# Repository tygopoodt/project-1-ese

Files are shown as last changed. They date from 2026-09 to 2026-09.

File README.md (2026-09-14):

<p align="center">
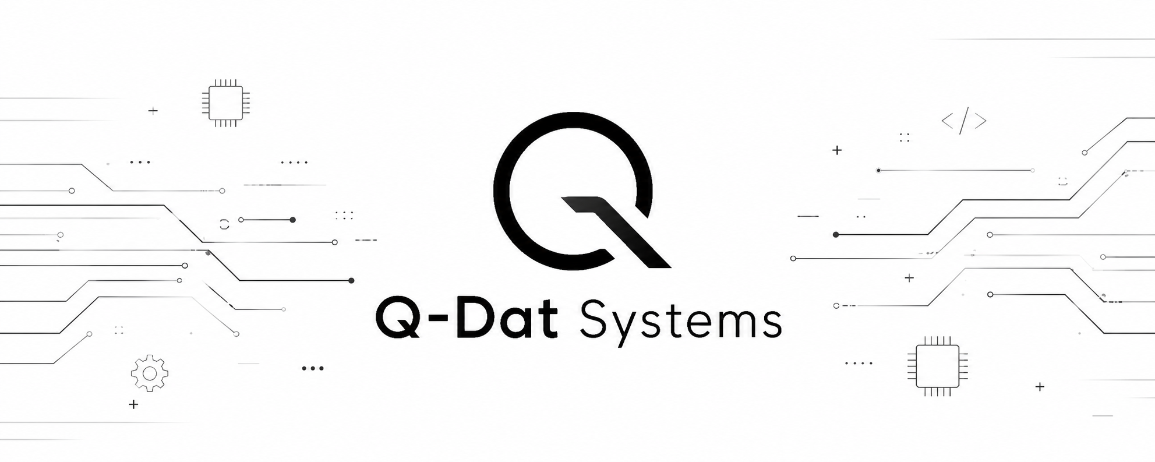
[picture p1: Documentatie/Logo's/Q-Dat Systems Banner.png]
Q-Dat Systems
  
</p>

<h1 align="center">Robot-car</h1>

<p align="center">
  <em>Project 1 NL &middot; Embedded Systems Engineering &middot; HAN</em>
</p>

<p align="center">
  
  
  
  
</p>

---

## Over het project

Transport wordt steeds verder geautomatiseerd. Voor opdrachtgever Robot-car-Gadgets
ontwikkelt **Q-Dat Systems** een prototype van de **Robot-car**: een autonoom rijdende
modelauto op basis van een ATmega328P.

De auto rijdt vooruit, achteruit en draait om zijn as, volgt een zwarte lijn op de vloer,
houdt afstand tot een voorganger en is via remote control te besturen. De motoren worden
met PWM via een L298N H-brug aangestuurd; bediening en tests lopen over de USART.

Het project beslaat twee perioden. In de eerste periode verkennen we de functionaliteit met
rapid prototyping in de Arduino IDE. In de tweede periode gaat dezelfde microcontroller
opnieuw op de tekentafel, nu in C met directe registermanipulatie.

## Repository

| Map | Inhoud |
| --- | --- |
| `Software/` | Firmware voor de ATmega328P |
| `Hardware/` | Schema's, componentkeuzes en het 3D-model van het chassis |
| `Documentatie/` | Functioneel ontwerp, MoSCoW-eisen, planning, notulen en huisstijl-templates |
| `Documentatie/Logo's/` | Logo's, banner en logo-animatie Q-Dat Systems |
| `Documentatie/Schetsen/` | UI-schetsen van bediening, displays en gedrag |
| `Documentatie/Frame-analyse/` | Analyse van frame, spoorbreedte en massa |
| `Documentatie/Simulatie Onderzoek/` | MATLAB-simulaties voor lijnvolgen en obstakeldetectie |
| `Documentatie/SchoolDocumenten_Project/` | Projecthandleiding, beoordelingsformulieren en richtlijnen |

## Kernvereisten

- **T1** ATmega328P als microcontroller
- **T2/T3** Programmeren in C, volgens de C-stijl- en programmeerrichtlijnen, code in het Engels
- **T4** DC-motoren via een L298N H-brug, snelheid geregeld met PWM
- **T5** Besturing en tests via de USART
- **T6** Voeding uit batterijen, met polariteits- en kortsluitbeveiliging
- **B1** Maximaal &euro;50,- aan aanvullende componenten

## Team

Projectgroep **Q-Dat Systems**:

Mohammed &middot; Tygo &middot; Floris &middot; Milan &middot; Mathijs &middot; Nathan

---

<p align="center">
  <sub>Q-Dat Systems &middot; Academie Engineering en Automotive &middot; Hogeschool van Arnhem en Nijmegen</sub>
</p>

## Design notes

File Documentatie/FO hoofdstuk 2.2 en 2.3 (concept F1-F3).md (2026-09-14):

# Functioneel ontwerp — aanvulling hoofdstuk 2.2 en 2.3

**Status:** concept, uitgewerkt voor F1, F2 en F3. Wordt aangevuld zodra F4 tot en met F7 zijn vastgesteld.
**Bron van de eisen:** Projecthandleiding PROJ1-V v1.0, §3.5 (concept technische eisen T1–T7 en budgeteis B1) en §3.7 en §3.11.
**Doel:** de twee subparagrafen die het Template productrapport v1.4 voor hoofdstuk 2 voorschrijft, maar die nu nog ontbreken.

---

## 2.2 Technische specificaties

Naast de functionele specificaties uit paragraaf 2.1 stelt de opdrachtgever een aantal aanvullende eisen aan het product zelf: de te gebruiken microcontroller, de programmeertaal, de manier waarop de motoren worden aangedreven en de wijze van voeding. Deze technische specificaties beschrijven waaraan het product moet voldoen, niet hoe wij dat gaan realiseren; die uitwerking volgt in hoofdstuk 3.

De nummering T1 tot en met T7 komt overeen met de concept technische eisen uit de projecthandleiding, zodat de opdrachtgever zijn eigen eisen terugvindt. T8 tot en met T11 zijn door ons toegevoegd omdat de functionele specificaties uit paragraaf 2.1 daar niet zonder kunnen. De kolom *Herleidbaar naar* verwijst naar de functionele specificatie die de betreffende technische eis mogelijk maakt.

### Tabel 2 — SMART technische specificaties

| # | MoSCoW | Omschrijving | Herleidbaar naar |
|---|---|---|---|
| T1 | M | De besturing van de robot-car wordt gerealiseerd met een ATmega328(p)-microcontroller. | F1, F2, F3 |
| T1.1 | M | In periode 1 wordt het tussenproduct via rapid prototyping gerealiseerd met de Arduino IDE op dezelfde ATmega328(p); in periode 2 wordt de microcontroller aangestuurd door rechtstreeks de registers te bewerken. | F1, F2, F3 |
| T2 | M | De software voor de microcontroller wordt geschreven in de programmeertaal C. | F1, F2, F3 |
| T3 | M | De C-code voldoet aan de programmeerrichtlijnen zoals aangeleerd in de opleiding (C-style programming guidelines v3.1). | F1, F2, F3 |
| T4 | M | De dc-motoren van de robot-car worden aangedreven via een H-brug, zodat beide draairichtingen per motor mogelijk zijn. | F1.1, F1.2 |
| T4.1 | M | Voor het regelen van de motorsnelheid wordt gebruikgemaakt van de PWM van de microcontroller; er wordt geen aanvullende hardware voor snelheidsregeling toegepast. | F1.3 |
| T4.2 | M | Voor de H-brug wordt gebruikgemaakt van een L298N dual H-bridge driverboard. | F1.1, F1.2 |
| T4.3 | M | De robot-car wordt aangedreven door de vier dc-motoren van het door de opdrachtgever geleverde chassis. | F1 |
| T5 | M | Voor testdoeleinden kan de robot-car bestuurd worden via de seriële interface, de USART van de ATmega328(p). | F1, F2.5 |
| T5.1 | M | Via de USART kan de robot-car vooruit en achteruit rijden. | F1.1 |
| T5.2 | M | Via de USART kan de robot-car links- en rechtsom draaien. | F1.2 |
| T5.3 | M | Via de USART kan de rijsnelheid van de robot-car worden ingesteld. | F1.3 |
| T5.4 | M | Via de USART kan de autonome mode worden gestart en gestopt. | F2.5 |
| T6 | M | Voor de voeding van de robot-car wordt gebruikgemaakt van batterijen. | F1, F2, F3 |
| T6.1 | M | De schakeling is beveiligd tegen het verkeerd om aansluiten van de voeding. | – |
| T6.2 | M | De batterijen zijn beveiligd tegen kortsluiting door een beveiliging die zo dicht mogelijk bij de batterij is geplaatst. | – |
| T6.3 | M | Een LED geeft aan dat de robot-car wordt gevoed; deze LED brandt continu zolang de robot-car is ingeschakeld. | F1, F2, F3 |
| T6.4 | M | De voedingsspanning van de microcontroller blijft binnen het door de fabrikant toegestane bereik, ook wanneer alle vier de motoren gelijktijdig maximaal worden belast. | F1, F2, F3 |
| T6.5 | C | De batterijspanning is voor de microcontroller meetbaar, zodat het batterijniveau kan worden weergegeven. | F5.4 |
| T7 | M | De achterzijde van de robot-car is voorzien van een reflector, zodat deze robot-car op zijn beurt door een andere robot-car gevolgd kan worden. | F3.2 |
| T8 | M | De robot-car meet de vrije ruimte recht vooruit met een afstandssensor. | F2.1 t/m F2.4, F3.2 |
| T8.1 | M | De afstandssensor heeft een meetbereik van ten minste 10 tot 50 cm. | F2.2, F3.2 |
| T8.2 | M | De afstandssensor levert ten minste 5 metingen per seconde. | F2.2 |
| T9 | M | De robot-car detecteert de te volgen lijn met een lijnsensor aan de onderzijde van het chassis. | F3.1 |
| T9.1 | M | De lijnsensor detecteert zwart tape van 1 tot 2 cm breed op het linoleum van de gang op de begane grond van gebouw R29. | F3.1 |
| T9.2 | M | De lijnsensor kan onderscheiden of de lijn zich links van, onder, of rechts van het midden van de robot-car bevindt, zodat de afwijking kan worden bijgestuurd. | F3.1 |
| T10 | M | De robot-car is voorzien van handbediening op de auto zelf, bestaande uit een display en bedieningstoetsen. | F5, F6 |
| T10.1 | M | Het display geeft vier regels gelijktijdig weer, volgens de regelindeling van figuur 2. | F5.1 t/m F5.4 |
| T10.2 | S | De bediening bestaat uit drie toetsen: omhoog, omlaag en OK. | F6 |
| T11 | C | Aan de achterzijde van de robot-car zitten twee LED's, links en rechts, die de draairichting aangeven. | F1.4 |

### Tabel 3 — Budgeteisen

| # | MoSCoW | Omschrijving | Herleidbaar naar |
|---|---|---|---|
| B1 | M | Het chassis met de vier dc-motoren wordt geleverd door de opdrachtgever. | T4.3 |
| B2 | M | De aanvullende kosten voor het prototype bedragen maximaal € 50,- aan onderdelen. Willen wij meer besteden, dan wordt dit vooraf met de tutor overlegd. | T8, T9, T10 |
| B3 | M | Kosten voor het gebruik van het Fablab worden meegenomen in de berekening van de uiteindelijke productiekosten, ook wanneer ze voor het project zelf niet in rekening worden gebracht. | – |

### Open punten bij de technische specificaties

1. **T5.4** — In de concepteisen staat T5.4 zonder omschrijving. Wij hebben deze ingevuld als "de autonome mode kan via de USART worden gestart en gestopt", aansluitend op F2.5. Graag bevestigen of dit is wat u bedoelde.
2. **H-brug** — In §3.5 van de projecthandleiding staat een L298N, in implementatietip 5 een L294n. Wij gaan uit van de L298N; graag bevestigen.
3. **Snelheidsmeting** — Op het beoordelingsformulier staat dat de robot-car sensoren heeft voor het meten van afstand *en snelheid*. In de concepteisen komt snelheidsmeting niet voor. Moet de werkelijke rijsnelheid gemeten worden, of volstaat het instellen van de snelheid via PWM (T4.1)?
4. **T10.1** — Wij stellen een display van vier regels voor, omdat F5.1 tot en met F5.4 samen vier gegevens moeten tonen. Gaat u hiermee akkoord?
5. **T6.5** — Het meten van de batterijspanning staat op Could, in lijn met F5.4. Als u het batterijniveau wel als vaste eis wilt, wordt dit een Must.

---

## 2.3 User interface

In deze paragraaf staat hoe de robot-car er voor de gebruiker uitziet en hoe hij zich gedraagt: welke bedieningselementen er zijn, wat er op het display verschijnt, en wat er aan de uitvoer verandert wanneer de gebruiker of de omgeving iets doet. De schetsen zijn een tweede weergave van dezelfde functionaliteit die in paragraaf 2.1 in tabelvorm staat, en zijn bedoeld om samen met de opdrachtgever vast te stellen dat wij hetzelfde beeld voor ogen hebben. De schetsen zijn niet op schaal en leggen geen componentkeuze vast; die volgt in hoofdstuk 3.

### Figuur 1 — Bedieningselementen en sensoren van de robot-car

*Bestand: `Documentatie/Schetsen/UI-01 Bedieningselementen Robot-car.svg`*

Bovenaanzicht en achteraanzicht van de robot-car met de plaats van de afstandssensor (T8), de lijnsensor (T9), het display en de bedieningstoetsen (T10), de batterijen (T6), de richting-LED's (T11), de voedings-LED (T6.3) en de reflector (T7). De genummerde legenda koppelt elk element aan de specificatie waaruit het voortkomt.

### Figuur 2 — Displayschermen en menustructuur

*Bestand: `Documentatie/Schetsen/UI-02 Displayschermen en menustructuur.svg`*

Deel A legt de vaste regelindeling van het display vast: regel 1 toont de actieve mode en het batterijniveau, regel 2 de rijrichting of de status, regel 3 de tijd in de huidige mode en regel 4 de totale gebruikstijd. Deze indeling is in elke mode gelijk; alleen de inhoud van regel 1 en 2 verandert. Deel B toont het hoofdmenu waarmee de gebruiker een mode kiest (F6) en de schermen die daarbij horen: Autonoom rijdend en Autonoom bij stilstand voor een obstakel (F2), en Slave volgend en Slave wachtend op de voorganger (F3). De schermen voor de handbediening (F4) volgen dezelfde indeling en worden bij F4 uitgewerkt.

### Figuur 3 — Invoer, uitvoer en gedrag van de richting-LED's

*Bestand: `Documentatie/Schetsen/UI-03 Invoer-uitvoer en LED-gedrag.svg`*

Deel A geeft in één overzicht weer welke invoer de robot-car krijgt (bedieningstoetsen, afstandssensor, lijnsensor, USART-commando's) en welke uitvoer hij daarop geeft (display, richting-LED's, voedings-LED, aandrijving). Deel B laat zien wat er met de uitvoer gebeurt als de invoer verandert: zolang de robot-car naar links draait knippert alleen de linker-LED met 50 ms aan en 50 ms uit, en die LED gaat direct uit zodra het draaien stopt (F1.4). De voedings-LED brandt onafhankelijk daarvan continu (T6.3).

### Figuur 4 — Gedrag op het parcours bij F2 en F3

*Bestand: `Documentatie/Schetsen/UI-04 Gedrag F2 autonoom en F3 slave.svg`*

Deel A toont de drie situaties van het autonoom rijden met de bijbehorende maten: doorrijden zolang er recht vooruit ten minste 30 cm vrij is (F2.1), remmen en stoppen bij een obstakel binnen 20 cm met minimaal 2 cm ruimte over (F2.3), en binnen 4 seconden een nieuwe richting kiezen door te draaien of maximaal 30 cm achteruit te rijden (F2.4). Deel B toont de slave mode: de robot-car blijft binnen 5 cm van de lijn (F3.1) en houdt 10 tot 50 cm afstand tot de voorganger, die aan de achterzijde een reflector draagt (F3.2, T7). Bij elke situatie staat wat het display op dat moment toont.

### Open punten bij de user interface

1. **Plaats van display en menu** — Wij gaan ervan uit dat het display en de toetsen op de auto zelf zitten, zoals in figuur 1. Als u ze liever in de afstandsbediening ziet, verandert figuur 1 en figuur 2.
2. **Regel 2 van het display** — In de concepteisen staat de snelheid op het display (F5.2); wij tonen daar nu de rijrichting en de mode. Wilt u de snelheid er alsnog bij, dan is een vijfde regel of een tweede scherm nodig.
3. **Wisselen van mode** — Mag de gebruiker tijdens het rijden van mode wisselen, of moet de robot-car daarvoor eerst stilstaan?
4. **Parcours** — Voor figuur 4 hebben wij de afmetingen van het testparcours en het lijnparcours nodig, en de afmetingen en het materiaal van de obstakels.

---

## Verwerken in het Word-document

De vier schetsen zijn SVG-bestanden. Word 2016 en later ondersteunt SVG rechtstreeks: **Invoegen → Afbeeldingen → Dit apparaat**, en daarna een bijschrift toevoegen via **Verwijzingen → Bijschrift invoegen**, zodat de figuurnummering automatisch meeloopt met de rest van het rapport. De tabellen staan ook als CSV in `Documentatie/Technische eisen MoSCoW.csv` en `Documentatie/Budgeteisen MoSCoW.csv`, in dezelfde opzet als de bestaande `Functionele eisen MoSCoW.csv`.

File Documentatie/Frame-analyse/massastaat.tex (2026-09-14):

\begin{tabular}{lrrrl}
\toprule
Component & $m$ [g] & $x_g$ achter as & $h$ [mm] & Plaats \\
\midrule
2 wielen & 60 & 0 & 32 & op de aandrijfas \\
2 motoren & 60 & 17 & 32 & huis 70 mm, 18 mm voor de as \\
frame + dek (3D-print) & 130 & 25 & 38 & PETG, topologisch geoptimaliseerd \\
accu 4$\times$AA & 110 & 55 & 54 & hoofddek, achter \\
ATmega328P Xplained Mini & 25 & -12 & 54 & hoofddek, voor \\
L298N-module & 27 & -30 & 80 & bovendek \\
breadboard + bedrading & 60 & 30 & 71 & bovendek \\
draadwerk en bevestiging & 30 & 20 & 55 &  \\
HC-SR04 & 10 & -45 & 58 & sensorbeugel \\
lijnsensor & 12 & -45 & 8 & onder de sensorbeugel \\
vrijloopwieltje & 15 & 75 & 14 &  \\
\midrule
\textbf{totaal} & \textbf{539} & \textbf{21.8} & \textbf{46.4} & \\
\bottomrule
\end{tabular}

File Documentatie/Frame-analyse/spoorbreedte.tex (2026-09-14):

\documentclass[10pt,a4paper]{article}
\usepackage[T1]{fontenc}
\usepackage[utf8]{inputenc}
\usepackage[dutch]{babel}
\usepackage[margin=20mm,top=18mm,bottom=18mm,headheight=18pt,headsep=5mm]{geometry}
\usepackage{amsmath,amssymb}
\usepackage{graphicx}
\usepackage{booktabs}
\usepackage{xcolor}
\usepackage{fancyhdr}
\usepackage[font=small,labelfont=bf,skip=3pt]{caption}
\usepackage{enumitem}
\providecommand{\num}[1]{#1}
\setlist{itemsep=1pt,topsep=3pt,parsep=0pt}
\setlength{\parskip}{4pt}
\setlength{\parindent}{0pt}
\definecolor{qdat}{HTML}{1a1a1a}
\definecolor{han}{HTML}{E6006E}

\input{resultaten}

\pagestyle{fancy}
\fancyhf{}
\renewcommand{\headrulewidth}{0.4pt}
\fancyhead[L]{\footnotesize Optimale spoorbreedte, massalimiet en bouwhoogte}
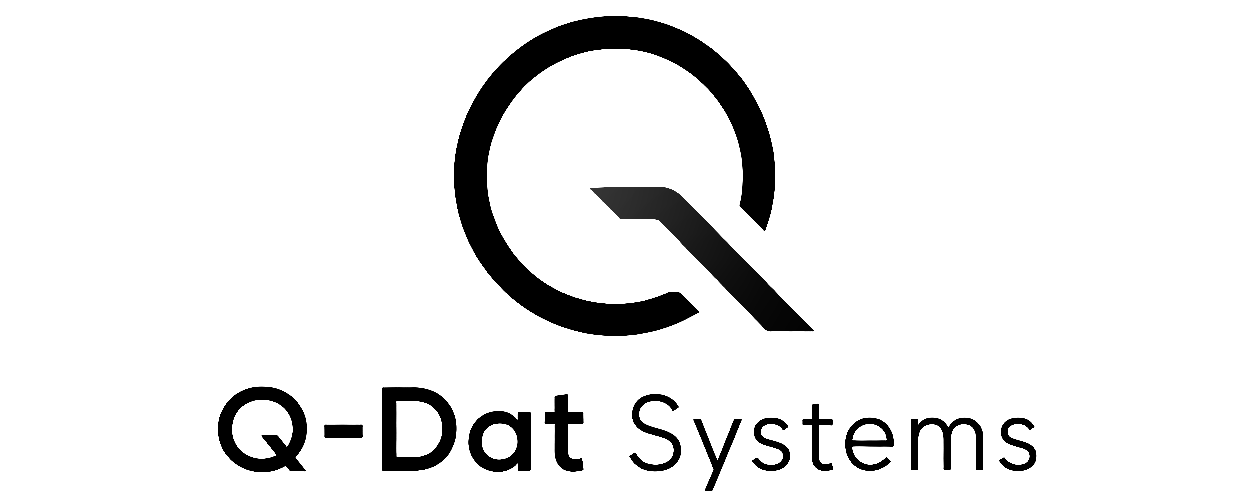
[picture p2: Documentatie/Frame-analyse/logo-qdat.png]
\fancyhead[R]{\raisebox{-1.1mm}{}}
\fancyfoot[C]{\footnotesize\thepage}

\begin{document}
\thispagestyle{plain}
\noindent
\begin{minipage}[b]{0.5\textwidth}%
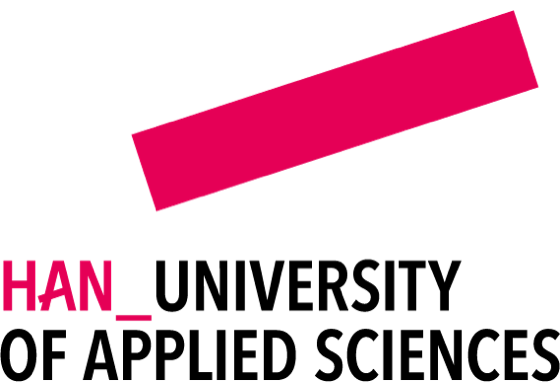
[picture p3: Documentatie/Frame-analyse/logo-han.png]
  %
\end{minipage}%
\begin{minipage}[b]{0.5\textwidth}%
  \raggedleft%
\end{minipage}

\vspace{3mm}\hrule\vspace{6mm}

{\LARGE\bfseries Optimale spoorbreedte, massalimiet en bouwhoogte}\\[2mm]
{\large Custom frame voor een differentieel aangedreven autonome robotauto}\\[3mm]
{\small Q-Dat Systems \quad$\cdot$\quad Project 1 Embedded Systems \quad$\cdot$\quad \today\\[1mm]
Opgesteld door \textbf{Claude Opus 5} in opdracht van Tygo Poodt, op basis van de 1:1
CAD-modellen van de componenten en de databladen van motor en driver.}

\vspace{3mm}\hrule\vspace{4mm}

\textbf{\large Onderzoeksvragen}
\begin{enumerate}[label=\textbf{\arabic*.},leftmargin=8mm]
\item Welke spoorbreedte $b$ is optimaal voor een zelf te ontwerpen frame?
\item Hoe zwaar mag de auto worden met de twee gegeven motoren?
\item Op welke hoogte komen de componenten, en hoe hoog mag het zwaartepunt worden?
\end{enumerate}

\vspace{2mm}
\fbox{\parbox{\dimexpr\textwidth-2\fboxsep-2\fboxrule}{%
\textbf{Conclusie.}\quad
\textbf{(1)} $b = \RbOpt$~mm, hart band tot hart band. De platte 4$\times$AA-houder past niet
tussen de motoren, dus staat alles achter elkaar op twee dekken en is de smalste uitvoering de
zuinigste; \RbOpt~mm is het smalst waarop de Xplained Mini nog op een dek past.\quad
\textbf{(2)} $m \le \RmAdvies$~g totaal. Van de \RUpack~V uit vier AA-cellen komt maar
\RUm~V aan de motor; het werkpunt van het beste rendement ligt op $u^* = \RkDuty$~\% van het
blokkeerkoppel. Het ontwerp weegt \Rmtotg~g, dus er is nog maar \RmRuimte~g over.\quad
\textbf{(3)} Hoofddek op \RzDeckEen~mm, bovendek op \RzDeckTwee~mm, totale hoogte
\RzTop~mm. Het zwaartepunt moet onder \RhMax~mm blijven; het zit nu op \Rhcg~mm, goed voor
nog \RmTopMax~g extra op het bovendek.
}}

\section{Meetgegevens}

\begin{minipage}[t]{0.48\textwidth}
\footnotesize
\begin{tabular}{@{}llr@{}}
\multicolumn{3}{@{}l}{\textbf{Uit de 1:1 CAD-modellen}}\\
\toprule
$D$ & wieldiameter & \RDw~mm \\
$w$ & bandbreedte & \Rwtyre~mm \\
$t$ & dikte tandwielkast & \Rtgb~mm \\
$e$ & hart band buiten de kastwand & \Rewheel~mm \\
$L_m$ & motorlengte & \RLmot~mm \\
 & Xplained Mini & 60$\times$75~mm \\
 & breadboard half-size & 55$\times$84~mm \\
 & L298N-module & 43$\times$43~mm \\
 & accu 4$\times$AA, plat & 58$\times$61~mm \\
\bottomrule
\end{tabular}
\end{minipage}\hfill
\begin{minipage}[t]{0.48\textwidth}
\footnotesize
\begin{tabular}{@{}llr@{}}
\multicolumn{3}{@{}l}{\textbf{Uit de databladen en aannames}}\\
\toprule
$\tau_s$ & blokkeerkoppel bij \RUbat~V & \RtauStallZes~mNm \\
$I_s$ & blokkeerstroom bij \RUbat~V & \RIstallZes~A \\
$I_0$ & onbelaste stroom & \RIfree~A \\
$n_0$ & onbelast toerental bij \RUbat~V & \RnNulZes~rpm \\
$U_{\text{pak}}$ & 4$\times$AA alkaline & \RUpack~V \\
$R_{\text{pak}}$ & inwendige weerstand & \RRpack~$\Omega$ \\
$\mu$ & wrijving band -- vloer & \Rmu \\
$C_{rr}$ & rolweerstand & \Rcrr \\
$N$ & encoderpulsen per wielomw. & \RNaxle \\
$\epsilon_b$ & tolerantie spoorbreedte & \Repsb~mm \\
$E_d$ & wieldiameterverschil L/R & \REd~\% \\
\bottomrule
\end{tabular}
\end{minipage}

\vspace{2mm}
De kinematica van een differentieelaandrijving legt vast waarom juist $b$ telt:
\begin{equation}
\Delta s = \tfrac{1}{2}(s_R + s_L), \qquad \Delta\theta = \frac{s_R - s_L}{b}
\label{eq:kin}
\end{equation}
Dit is exact zolang de wielen zuiver rollen. De motorafstand $g$ (vrije ruimte tussen de
tandwielkasten) vertaalt naar $b$ via
\begin{equation}
b = g + 2(t+e) = g + \RbMinPack~\text{mm},\qquad
B_{\text{frame}} = g + 2t,\qquad B_{\text{buiten}} = b + w
\label{eq:pak}
\end{equation}

\begin{figure}[htbp]
\centering

\caption{Symbolen. Oorsprong midden op de aandrijfas, vloerniveau, $x$ naar voren.}
\end{figure}

\section{Vraag 1: de optimale spoorbreedte}

\subsection{Wat breder maken oplevert}
Alle odometriefouten schalen met $1/b$: de hoekstap per encoderpuls, de fout door een
tolerantie $\epsilon_b$ in de effectieve spoorbreedte, en de koersdrift door een
diameterverschil $E_d$ over een afstand $L$:
\begin{equation}
\delta\theta = \frac{\pi D}{N b},\qquad
\frac{\Delta\theta}{\theta} = \frac{\epsilon_b}{b},\qquad
y(L) = \frac{L^2 E_d}{2b}
\label{eq:odo}
\end{equation}
Bij $b = \RbOpt$~mm geeft dat \RquantOpt$^\circ$ per puls, \RcalOpt$^\circ$ na een bocht van
$90^\circ$ en \RdriftOpt~mm drift per meter. Zijdelings kantelen speelt niet: de auto glijdt
eerder weg dan dat hij kiepert zodra $b \ge 2\mu h = \RbRoll$~mm.

\emph{Belangrijker dan de breedte:} met de sleufschijf op de motoras in plaats van op de
wielas gaat $\delta\theta$ van \RquantOpt$^\circ$ naar \RquantShaft$^\circ$, een factor 48.
Daarmee vervalt het sterkste argument om breder te bouwen dan strikt nodig.

\subsection{Wat breder maken kost}
Voor elke $b$ is de bruikbare dekbreedte bepaald en is met een plankjes-indeling
(90$^\circ$ draaien toegestaan, \Rclear~mm speling) de kortste framelengte gezocht waarop de
vier componenten op \emph{twee} dekken passen. Drie dekken telt niet: dat tilt $h$ op en
vreet de kantelmarge uit~\eqref{eq:stat} op. Het frame-oppervlak $A(b) = L(b)\cdot
B_{\text{frame}}(b)$ heeft daardoor een minimum:
\begin{equation}
A(\RbArea) = \RAframe~\text{cm}^2
\quad\text{tegen}\quad
\RAframeSmal~\text{cm}^2 \text{ smaller en } \RAframeBreed~\text{cm}^2 \text{ bij } 152~\text{mm}
\label{eq:area}
\end{equation}
De platte 4$\times$AA-houder is \RaccuW~mm breed en past pas tussen de motoren vanaf
$b = \RbAccu$~mm --- veel te breed. Hij gaat dus hoe dan ook op een dek, en dan past er niets
meer naast elkaar: met een bruikbare dekbreedte van \RWuOpt~mm staat alles achter elkaar en ligt
de framelengte vast op \RxfOpt~mm vóór plus \Rxrear~mm achter de as. Het oppervlak
$A = L\cdot B_{\text{frame}}$ is dan alleen nog evenredig met de breedte, dus wint de smalste
uitvoering --- en die wordt begrensd door de Xplained Mini: die is 60~mm breed en past pas op
een dek vanaf $b = \RbArea$~mm. Breder maken kost recht evenredig meer frame
(\RAframeGain~\% bij 152~mm) voor \RquantWinst~\% betere hoekresolutie: een slechte ruil. De
draaicirkel blijft tot $b = \RbSweptMax$~mm gewoon $\varnothing\,\RDswept$~mm.

\begin{figure}[htbp]
\centering

\caption{Links: onder \RbAccu~mm groeit het frame in de lengte. Midden: daardoor een minimum
in het oppervlak bij \RbArea~mm. Rechts: breder maken kost tot \RbSweptMax~mm niets aan
draaicirkel, wel aan buitenmaat.}
\end{figure}

\begin{figure}[htbp]
\centering

\caption{De drie foutbronnen uit~\eqref{eq:odo}, alle evenredig met $1/b$.}
\end{figure}

\section{Vraag 2: hoeveel massa mogen de motoren trekken}

\subsection{Motormodel}
De motor krijgt niet de pakspanning. De vier AA-cellen zakken in onder belasting en de
L298 slikt een vrijwel vaste verzadigingsval. Met twee motoren die elk $I$ trekken geldt
\begin{equation}
U_m = U_{\text{pak}} - 2I\,R_{\text{pak}} - \bigl(V_{d0} + V_{d1}I\bigr)
\qquad\Longrightarrow\qquad U_m = \RUm~\text{V}
\label{eq:voeding}
\end{equation}
Van de \RUpack~V blijft dus \RUm~V over; de L298 alleen kost al \RVdrop~V. Omdat alle
motorconstanten lineair met de klemspanning schalen, is dit een vaste-puntiteratie: het
werkpunt bepaalt de stroom en de stroom bepaalt de spanning.

Een gelijkstroommotor met borstels bij klemspanning $U_m$ heeft een lineaire
koppel-toerentalkarakteristiek. Met $u = \tau/\tau_s$ als belastingsgraad aan de uitgaande as:
\begin{equation}
\tau(u) = u\,\tau_s, \qquad
\omega(u) = \omega_0\,(1-u), \qquad
I(u) = I_0 + (I_s - I_0)\,u
\label{eq:motor}
\end{equation}
Blokkeren ($u=1$) is geen werkpunt: alle elektrische energie wordt dan warmte. Het zinvolle
duurzame werkpunt is dat van het beste rendement, want dat levert het meeste nuttige werk per
ampère\-uur accu en produceert daarmee ook de minste warmte. Met
$\eta(u) = \tau\omega/(UI)$ geldt
\begin{equation}
\eta(u) = \frac{\tau_s\,\omega_0\;u(1-u)}{U\,\bigl(I_0 + (I_s-I_0)u\bigr)},
\qquad
\frac{\mathrm{d}\eta}{\mathrm{d}u} = 0
\;\Longrightarrow\;
(I_s-I_0)\,u^2 + 2I_0\,u - I_0 = 0
\label{eq:eta}
\end{equation}
De fysisch zinvolle wortel is
\begin{equation}
\boxed{\;u^* = \frac{\sqrt{I_0 I_s} - I_0}{I_s - I_0}\;}
\qquad\Rightarrow\qquad
u^* = \frac{\sqrt{\RIfree \cdot \RIstallEen} - \RIfree}{\RIstallEen - \RIfree} = \RkDuty~\%
\label{eq:ustar}
\end{equation}
Invullen in~\eqref{eq:motor}, met de constanten geschaald naar $U_m$, geeft het werkpunt per
motor: koppel \RtauCont~mNm, toerental \RnCont~rpm (dus $v = \omega r = \RvCont$~m/s),
stroom \RIcontEen~A, rendement \RetaCont~\% inclusief de tandwielkast. Voor twee motoren
samen is dat \RPmechCont~W nuttig uit \RPelekCont~W elektrisch.

\subsection{Massalimiet}
De duurzame trekkracht van twee motoren aan de wielomtrek is
\begin{equation}
F_c = \frac{2\,u^*\tau_s}{r} = \RFcont~\text{N}
\label{eq:Fc}
\end{equation}
De rijweerstand van een auto met massa $m$ op een helling $\theta$ bij versnelling $a$ is
$F = m\bigl(a + g(C_{rr}\cos\theta + \sin\theta)\bigr)$. Gelijkstellen geeft
\begin{equation}
\boxed{\;m_{\max}(a,\theta) = \frac{2\,u^*\tau_s / r}{a + g\,(C_{rr}\cos\theta + \sin\theta)}\;}
\label{eq:massa}
\end{equation}
Grip begrenst de massa niet: de eis $F \le \mu\sigma m g$ heeft $m$ aan beide kanten, want
zwaarder betekent evenveel méér grip. Alleen het koppel is bepalend.

\begin{center}
\footnotesize
\begin{tabular}{@{}llr@{}}
\toprule
Rijgeval & & $m_{\max}$ \\
\midrule
vlakke vloer, $a = 0{,}5$~m/s$^2$ & ruim & \RmMaxVlak~g \\
vlakke vloer, $a = 1{,}0$~m/s$^2$ & vlot optrekken & \RmMaxSnel~g \\
\textbf{drempel $5^\circ$, $a = 0{,}3$~m/s$^2$} & \textbf{maatgevend} & \textbf{\RmAdvies~g} \\
helling $10^\circ$, $a = 0{,}3$~m/s$^2$ & zwaar & \RmMaxTien~g \\
\bottomrule
\end{tabular}
\end{center}

Aanhouden: \textbf{\RmAdvies~g}. Het ontwerp weegt nu \Rmtotg~g (\RmComp~g componenten,
\RmFrameNu~g frame), dus er is nog maar \RmRuimte~g over en het frame mag hooguit
\RmFrameMax~g worden. Dat is krap: houd het printvolume laag en weeg de gebouwde auto na.
De stroom blijft \RIcontEen~A per motor, ruim binnen de 2~A per L298-kanaal.

\textbf{De grootste winst zit in de driver.} De L298 kost \RVdrop~V van de \RUpack~V, oftewel
een kwart van het beschikbare vermogen. Een MOSFET-driver (bijvoorbeeld TB6612FNG, samen zo'n
0,5~V val) brengt $U_m$ van \RUm~V naar \RUmMos~V: \RmMosWinst~\% meer trekkracht,
\RmMosVijf~g in plaats van \RmAdvies~g, en \RvMos~m/s in plaats van \RvCont~m/s. Dat is
goedkoper dan gewicht besparen.

\begin{figure}[htbp]
\centering

\caption{Links: de karakteristiek~\eqref{eq:motor} met het werkpunt uit~\eqref{eq:ustar}.
Midden: $m_{\max}$ volgens~\eqref{eq:massa}. Rechts: het massabudget.}
\end{figure}

\section{Vraag 3: op welke hoogte de componenten komen}

De verticale opbouw ligt grotendeels vast zodra de motor gekozen is. De aandrijfas zit op
$r = \Rrw$~mm; het motorhuis is \Rhmot~mm hoog en symmetrisch om die as, dus van
\RzMotLo~mm tot \RzMotHi~mm. Het hoofddek moet daaroverheen: met een plaat van 3~mm komt de
bovenkant op \RzDeckEen~mm. Het hoogste onderdeel daarop is de L298N met koellichaam
(\RhLTweeNegenAcht~mm), dus het bovendek komt op \RzDeckTwee~mm --- afstandbussen van
\RhStandoff~mm --- en de bovenkant van het breadboard op \RzTop~mm.

De enige echte vrijheid is hoe zwaar je bovenin bouwt, en die wordt begrensd door de
kantelmarge uit~\eqref{eq:stat}:
\begin{equation}
a_{\text{kantel}} = g\,\frac{x_g}{h} \ge 0{,}4\,g
\quad\Longrightarrow\quad
h \le \frac{x_g}{0{,}4} = \RhMaxPitch~\text{mm}
\qquad\text{(zijdelings: } h \le \tfrac{b}{2\mu} = \RhMaxRoll\text{ mm, ruimer)}
\label{eq:hoogte}
\end{equation}
Het ontwerp zit op $h = \Rhcg$~mm en heeft dus \RhMarge~mm marge. Vertaald naar massa mag er
nog \textbf{\RmTopMax~g} bij op het bovendek voordat $h$ de grens raakt. Dat is minder dan de
\RmRuimte~g die het motorbudget nog toelaat: \emph{boven het bovendek is de hoogte eerder op dan
het gewicht.} Zware uitbreidingen horen dus laag, bij voorkeur in het kanaal naast de accu.

Twee maten volgen nog uit de opbouw. De bodemvrijheid is \RclearGround~mm (de onderkant van de
accu is het laagste punt), goed voor een hellingdoorgang van \Rbreakover$^\circ$. En de
HC-SR04 op \RzSRvier~mm met een halve openingshoek $\beta = 7{,}5^\circ$ verlicht de vloer pas
vanaf $R = z/\tan\beta = \RRfloor$~mm; daarbuiten zijn vloerechos mogelijk. Monteer hem zo hoog
als de zwaartepunteis toelaat en kantel hem een paar graden omhoog.

\begin{figure}[htbp]
\centering

\caption{Links: de verticale opbouw op schaal. Rechts: het zwaartepunt loopt tegen de grens
uit~\eqref{eq:hoogte} aan bij \RmTopMax~g extra op het bovendek.}
\end{figure}

\section{Randvoorwaarden die hieruit volgen}

\subsection{Plaats van het vrijloopwiel}
Statisch evenwicht om de aandrijfas geeft het gewichtsaandeel $\sigma$ op de aandrijfwielen,
de gevoeligheid daarvan voor bouwtoleranties, en de vertraging waarbij het wieltje loskomt:
\begin{equation}
\sigma = 1 - \frac{x_g}{d},
\qquad
\frac{\partial\sigma}{\partial x_g} = -\frac{1}{d},
\qquad
a_{\text{kantel}} = g\,\frac{x_g}{h}
\label{eq:stat}
\end{equation}
$d$ valt uit $a_{\text{kantel}}$ weg: de kantelmarge hangt alleen van $x_g$ en $h$ af. Met
$x_g = \Rxg$~mm en $h = \Rhcg$~mm is die \RaLiftG~$g$, ruim boven de eis van 0,4~$g$. De
grenzen op $d$ komen dus uit de gevoeligheid ($\le$ 1,5 procentpunt per mm, dus
$d \ge \RdSens$~mm) en de draaicirkel ($\le$ 200~mm, dus $d \le \RdMaxFoot$~mm). Gekozen:
$d = \RdOpt$~mm, waarmee $\sigma = \RsigmaOpt$~\%.

\begin{figure}[htbp]
\centering

\caption{Lastverdeling, gevoeligheid en kantelmarge volgens~\eqref{eq:stat}.}
\end{figure}

\subsection{Twee motoren, geen vier}
\begin{center}
\footnotesize
\begin{tabular}{@{}lrr@{}}
\toprule
 & 2 aangedreven wielen & 4 aangedreven wielen \\
\midrule
grip $\mu\sigma mg$ resp. $\mu mg$ & \RFtracTwee~N & \RFtracVier~N \quad(+\RtracGain~\%) \\
blokkeerstroom per L298-kanaal & \RIstallEen~A & \RIchanVier~A \quad(limiet 2~A) \\
verlies aan schuifwrijving bij spinnen & \RscrubTwee~\% & \RscrubVier~\% \\
geldigheid van~\eqref{eq:kin} & exact & ondergrond- en snelheidsafhankelijk \\
\bottomrule
\end{tabular}
\end{center}
Nodig is \RFreqNul~N vlak en \RFreqTien~N op $10^\circ$; met twee wielen is \RFtracTwee~N
beschikbaar, marge \RmarginNul{} resp.\ \RmarginTien. De extra grip van vier motoren is dus
niet nodig, en kost de exactheid van~\eqref{eq:kin} --- voor een auto die op dead reckoning
vaart de duurste post.

\section{Bouwmaten}

\begin{minipage}[t]{0.44\textwidth}
\footnotesize\vspace{0pt}
\begin{tabular}{@{}llr@{}}
\toprule
$b$ & spoorbreedte & \textbf{\RbOpt~mm} \\
$m$ & maximale massa & \textbf{\RmAdvies~g} \\
\midrule
$g$ & ruimte tussen de kasten & \RgapOpt~mm \\
 & frame naast de banden & \RbfWheel~mm \\
 & frame ervoor en erachter & \RframeWOpt~mm \\
 & buitenmaat over de banden & \RtotalWOpt~mm \\
$d$ & naloopafstand & \RdOpt~mm \\
$x_g$ & zwaartepunt achter de as & \Rxg~mm \\
$h$ & hoogte zwaartepunt & $\le$ \Rhcg~mm \\
$\varnothing$ & draaicirkel & \RDswept~mm \\
$v$ & rijsnelheid in het werkpunt & \RvCont~m/s \\
\midrule
 & hoofddek (bovenkant) & \RzDeckEen~mm \\
 & bovendek (bovenkant) & \RzDeckTwee~mm \\
 & afstandbussen ertussen & \RhStandoff~mm \\
 & totale bouwhoogte & \RzTop~mm \\
 & bodemvrijheid & \RclearGround~mm \\
\bottomrule
\end{tabular}
\end{minipage}\hfill
\begin{minipage}[t]{0.53\textwidth}
\vspace{0pt}
\begin{enumerate}[leftmargin=5mm]
\item \textbf{Naast de banden mag het frame maar \RbfWheel~mm breed zijn}: tussen kastwand en
band zit \RclearTyre~mm. Ervoor en erachter mag \RframeWOpt~mm. Kost niets: het breedste
onderdeel is 60~mm en het bruikbare dek is \RWuOpt~mm.
\item \textbf{Meet $e$ na met de schuifmaat.} De \Rewheel~mm uit~\eqref{eq:pak} komt uit de
CAD; 2~mm fout verschuift $b$ met 4~mm.
\item \textbf{Sleufgaten} voor het vrijloopwiel, $\pm 8$~mm in de rijrichting. Patroon
\RholeX$\times$\RholeY~mm, de \RholeX{} in de lengte.
\item \textbf{Rond de achterkant af} langs de boog met straal $d+15$~mm: $\varnothing\,\RDswept$
in plaats van $\varnothing\,\RDsweptSquare$~mm.
\item \textbf{Accu laag en achter} in het kanaal van \RgapOpt~mm: drukt $h$ omlaag en $x_g$
omhoog, beide gunstig volgens~\eqref{eq:stat}.
\item \textbf{Encoderschijf op de motoras}, niet op de wielas.
\end{enumerate}
\end{minipage}

\begin{figure}[htbp]
\centering

\caption{Indeling op schaal, met de versmalling naar \RbfWheel~mm ter hoogte van de banden.}
\end{figure}

\vspace{1mm}\hrule\vspace{1mm}
{\footnotesize \textbf{Geldigheid.} Alle getallen komen uit \texttt{analyse.py} in dezelfde
map, dat ook de figuren en \texttt{resultaten.tex} genereert. Het blokkeerkoppel
\Rtaustall~mNm is een databladwaarde; opgaven voor deze motorklasse lopen van 35 tot 80~mNm en
$m_{\max}$ schaalt daar recht evenredig mee. De wrijvingscoëfficiënten gelden voor een gladde
vloer. De massalimiet is berekend voor een drempel van $5^\circ$; op een volledig vlakke baan
mag de auto tot \RmMaxVlak~g wegen.}

\end{document}

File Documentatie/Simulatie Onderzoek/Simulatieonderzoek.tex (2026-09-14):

\documentclass[10pt,a4paper]{article}
\usepackage[T1]{fontenc}
\usepackage[utf8]{inputenc}
\usepackage[dutch]{babel}
\usepackage[margin=20mm,top=18mm,bottom=18mm,headheight=18pt,headsep=5mm]{geometry}
\usepackage{amsmath,amssymb}
\usepackage{graphicx}
\usepackage{booktabs}
\usepackage{xcolor}
\usepackage{fancyhdr}
\usepackage[font=small,labelfont=bf,skip=3pt]{caption}
\usepackage{enumitem}
\usepackage{float}
\setlist{itemsep=1pt,topsep=3pt,parsep=0pt}
\setlength{\parskip}{4pt}
\setlength{\parindent}{0pt}
\definecolor{qdat}{HTML}{1a1a1a}
\graphicspath{{resultaten/}{../Frame-analyse/}}

\input{resultaten/resultaten_lijn}
\input{resultaten/resultaten_obst}
% terugval als resultaten_obst.tex nog van een oudere run is
\providecommand{\ObstAlfaKruisLo}{16}
\providecommand{\ObstAlfaKruisHi}{30}

\pagestyle{fancy}
\fancyhf{}
\renewcommand{\headrulewidth}{0.4pt}
\fancyhead[L]{\footnotesize Simulatieonderzoek lijnvolgen en obstakeldetectie}
\fancyhead[R]{\raisebox{-1.1mm}{}}
\fancyfoot[C]{\footnotesize\thepage}

\begin{document}
\thispagestyle{plain}
\noindent
\begin{minipage}[b]{0.5\textwidth}%
  %
\end{minipage}%
\begin{minipage}[b]{0.5\textwidth}%
  \raggedleft%
\end{minipage}

\vspace{3mm}\hrule\vspace{6mm}

{\LARGE\bfseries Simulatieonderzoek lijnvolgen en obstakeldetectie}\\[2mm]
{\large Optimale sensorparameters voor de robot-car (eisen F2 en F3.1)}\\[3mm]
{\small Q-Dat Systems \quad$\cdot$\quad Project 1 Embedded Systems \quad$\cdot$\quad \today\\[1mm]
Opgesteld door \textbf{Claude Opus 5} in opdracht van Tygo Poodt. Alle getallen in dit document
komen rechtstreeks uit \texttt{onderzoek\_lijnvolgen.m} en \texttt{onderzoek\_obstakels.m}.}

\vspace{3mm}\hrule\vspace{4mm}

\textbf{\large Onderzoeksvragen}
\begin{enumerate}[label=\textbf{\arabic*.},leftmargin=8mm]
\item \emph{Lijnvolgen (F3.1).} Hoe ver voor de aandrijfas en met welke onderlinge afstand moeten de
  vier lijnsensoren zitten, en met welke regelaar volgt de auto de lijn het snelst binnen 5~cm?
\item \emph{Obstakels (F2).} Welke opstelling van de HC-SR04 en welk gedrag (snelheid, stopafstand,
  meetfrequentie, filter, remmen, draaien) geven de grootste kans op een botsingsvrije rit van
  2~minuten, zo snel mogelijk?
\end{enumerate}

\vspace{2mm}
\fbox{\parbox{\dimexpr\textwidth-2\fboxsep-2\fboxrule}{%
\textbf{Conclusie.}\quad
\textbf{(1)} De winst zit in de regelaar, niet in de sensorplaatsing. Met de geoptimaliseerde
PD-regelaar ($K_p = \LijnBestKp$~rad/s per m, $v_{\max} = \LijnBestVmax$~m/s) rijdt de auto het
testparcours in \LijnBestTpar~s in plaats van \LijnBaseTpar~s, met ten hoogste \LijnBestEmax~mm
afwijking (eis: 50~mm); de huidige regelaar komt tot \LijnBaseEmax~mm en haalt F3.1 dus niet. De
sensorbalk mag overal tussen 45 en 80~mm voor de aandrijfas zitten, met een steek van 8 tot 15~mm; het
optimum is $L = \LijnBestL$~mm en $s = \LijnBestSteek$~mm ($= w/1{,}5$: de steek die de lijnpositie in
gelijke stappen meet).\quad
\textbf{(2)} Eén HC-SR04 recht vooruit is voor F2 niet genoeg: hij ziet op de stopafstand maar
\ObstBbeschA--\ObstBbeschB~mm van de 143~mm brede neus, en een muur of kist die schuin staat geeft
geen echo. Het huidige ontwerp rijdt in \ObstHuidigPv~\% van de gesimuleerde ritten 2~minuten
zonder botsing. Beide bestelde HC-SR04's gekruist gebruiken (\texttt{kruis2}) werkt duidelijk het
best: in een rommelige ruimte \ObstBestZonderPv~\% botsingsvrij zonder encoders en \ObstBestPv~\% met
(95\%-interval \ObstBestPvLo--\ObstBestPvHi~\%); dat verschil valt binnen de ruis van de optimalisatie.
De kans dat de F2-test (2 van 3 ritten goed) slaagt is daarmee 51 tot 76~\%. De grootste onzekerheid is tot welke hoek een vlak nog een echo geeft; die moet
eerst aan de echte auto gemeten worden.
}}

\section{Opzet: één rekenkern, twee onderzoeken}

Beide simulaties gebruiken dezelfde kern (map \texttt{model/}), zonder graphics, zodat duizenden ritten
parallel kunnen draaien. De 3D-weergave (\texttt{demo\_*.m}) speelt achteraf een doorgerekende rit
af en laadt de carrosserie via \texttt{auto\_3d\_model.m}; een beter 3D-model verandert alleen dat
bestand. Alle maten en aannames staan in \texttt{qdat\_parameters.m}, elk met de bron erbij.

\textbf{Voertuig.} Assenstelsel: oorsprong midden op de aandrijfas, $x$ naar voren, $y$ naar links.
Differentiële aandrijving (Siegwart e.a., hoofdstuk~3):
\begin{equation}
v = \tfrac12 (v_R + v_L), \qquad \omega = \frac{v_R - v_L}{b}, \qquad
\dot x = v\cos\theta,\quad \dot y = v\sin\theta,\quad \dot\theta = \omega
\label{eq:kin}
\end{equation}
\textbf{Motor.} Per wiel een eerste-ordemodel met dode zone $u_{dz}$ en versterking $k_i$
(accuspanning, verschil links/rechts), begrensd op de grip $a_{\text{slip}} = \mu\sigma g$:
\begin{equation}
\tau_m \frac{dv_i}{dt} = k_i\, u_{\text{eff},i}\, v_0 - v_i,\qquad
u_{\text{eff}} = \operatorname{sgn}(u)\,\frac{\max(|u| - u_{dz},\,0)}{1-u_{dz}},\qquad
\tau_m = \frac{J_{eq}\,\omega_0}{\tau_s} = \frac{m r^2 \omega_0}{2\tau_s}
\label{eq:motor}
\end{equation}
Met de motorgegevens uit de frame-analyse ($U_m = 4{,}25$~V aan de klemmen) is $v_0 = \LijnVnul$~m/s
en $\tau_m = \LijnTaum$~ms. De regelaar stuurt een 8-bits PWM-waarde en compenseert de dode zone
met een schatting; de echte dode zone verschilt per run.

\textbf{Onzekerheid.} Een regelaar die alleen werkt in een perfecte simulatie is waardeloos
(Jakobi 1995; Tobin 2017). Elke rit krijgt daarom een eigen trekking van alles wat niet met een
schuifmaat na te meten is (\texttt{variatie\_trekken.m}):

\begin{center}\footnotesize
\begin{tabular}{@{}lll@{}}
\toprule
grootheid & variatie per rit & waarom \\
\midrule
accuspanning (versterking beide motoren) & 85--105~\% & lege tot volle accu \\
verschil motor links/rechts & $\pm$5~\% (lijnvolgen), $\pm$1~\% (F2, gekalibreerd) & goedkope TT-motoren \\
dode zone $u_{dz}$ & 10--22~\% PWM & aanname, meten \\
motortijdconstante $\tau_m$ & 80--130~\% & wrijving tandwielkast \\
effectieve spoorbreedte $b$ & $\pm$3~\% & contactvlak band \\
sensorversterking, -offset, -drempel & 8~\%, 4~\%, $\pm$0{,}08 per kanaal & potmeters LM393 \\
tapebreedte, breedte lichtvlek & $\pm$1~mm, 80--130~\% & \\
halve openingshoek HC-SR04 $\beta$ & 7{,}5--15° & datablad noemt 15° en 30° \\
grootste invalshoek met echo $\gamma_{\max}$ & 30--50° & aanname, \textbf{meten} \\
kans op gemiste echo & 0--4~\% & \\
\bottomrule
\end{tabular}
\end{center}

\textbf{Optimaliseren.} Er is geen Optimization Toolbox nodig: random search met daarna twee rondes
lokale verfijning rond de beste drie kandidaten (\texttt{optimalisatie/}). Bij 5 tot 13 parameters werkt
dat goed en het laat zich perfect paralleliseren; CMA-ES (Hansen 2016) is overwogen maar niet nodig
gebleken. Elke kandidaat rijdt op exact dezelfde banen met dezelfde afwijkingen, zodat verschillen door
de instellingen komen en niet door toeval. Het optimum wordt daarna getoetst op banen en ruimtes die de
optimizer nooit heeft gezien.

% =====================================================================
\section{Simulatie 1: lijnvolgen (F3.1)}

\subsection{Sensormodel}
Een TCRT5000 kijkt naar een lichtvlek op de vloer. Benader die vlek als een Gaussische vlek met breedte
$\sigma$; het deel dat op tape van breedte $w$ valt, als het midden van de vlek op afstand $d$ van de
tapehartlijn staat, is
\begin{equation}
c(d) = \tfrac12\left[\operatorname{erf}\!\left(\frac{w/2 - d}{\sqrt2\,\sigma}\right)
+ \operatorname{erf}\!\left(\frac{w/2 + d}{\sqrt2\,\sigma}\right)\right]
\label{eq:dekking}
\end{equation}
Het signaal is $s_i = g_i\,c(d_i) + o_i + \text{ruis}$; de comparator van de module maakt daar
$b_i = [s_i > \vartheta_i]$ van. De positie van de lijn onder de balk is het zwaartepunt van de actieve
sensoren, $\hat e = \sum y_i b_i / \sum b_i$. Analoog uitlezen (ADC) gebruikt $s_i$ zelf als gewicht.

\subsection{Steek: de lijnpositie in gelijke stappen meten}
Bij drempel $\tfrac12$ en $\sigma \ll w$ springt sensor $i$ om bij $e = y_i \pm w/2$. Met
$y_i = \bigl(i - \tfrac{N+1}{2}\bigr)s$ zijn dat twee roosters met steek $s$, ten opzichte van elkaar
verschoven over $w \bmod s$. De stappen in $\hat e$ zijn dus afwisselend $w \bmod s$ en
$s - (w \bmod s)$, en alleen gelijk ($= s/2$) als
\begin{equation}
\frac{w}{s} = k + \tfrac12 \quad\Longrightarrow\quad s = \frac{w}{1{,}5} = \LijnSteekUni~\text{mm}
\quad (k = 1,\ w = 19~\text{mm}),
\qquad e_{\text{bereik}} = \frac{(N-1)\,s}{2} + \frac{w}{2}
\label{eq:steek}
\end{equation}
Is $s > w$, dan ontstaan er posities waar geen enkele sensor de lijn ziet. De huidige plaatsing
($-22, -7, 7, 22$~mm) geeft stappen van 4 tot 15~mm (figuur~\ref{fig:sensor}b).

\begin{figure}[H]
\centering

\caption{(a) Dekkingsgraad \eqref{eq:dekking}. (b) Geschatte tegen werkelijke lijnpositie bij
digitaal uitlezen: de huidige plaatsing meet in ongelijke stappen, steek $w/1{,}5$ in gelijke.
(c) Analoog uitlezen interpoleert tussen de sensoren.}
\label{fig:sensor}
\end{figure}

\subsection{Waarom de sensorbalk vóór de as moet zitten: een lineair model}
Zij $e$ de zijdelingse afwijking van de aandrijfas ten opzichte van de lijn, $\psi$ de koersfout en
$\kappa$ de kromming van de lijn. Een sensorbalk op afstand $L$ voor de as meet
$e_s \approx e + L\psi - \tfrac12 L^2\kappa$. Met $\dot e = v\psi$, $\dot\psi = \omega - v\kappa$ en een
P-regelaar $\omega = -K e_s$ volgt
\begin{equation}
\ddot e + K L\,\dot e + K v\, e = v\kappa\left(\tfrac12 K L^2 - v\right)
\;\Longrightarrow\;
\omega_n = \sqrt{Kv},\quad \zeta = \frac{L}{2}\sqrt{\frac{K}{v}},\quad
e_{ss} = \kappa\left(\frac{L^2}{2} - \frac{v}{K}\right)
\label{eq:lin}
\end{equation}
De look-ahead $L$ werkt dus als demping, net als een D-term. De keuze
\begin{equation}
K^* = \frac{2v}{L^2} \quad\Longrightarrow\quad e_{ss} = 0 \ \text{in elke bocht},\qquad
\zeta = \frac{1}{\sqrt2},\qquad \omega_n = \frac{\sqrt2\, v}{L}
\label{eq:kster}
\end{equation}
geeft tegelijk nul blijvende fout in een bocht én de klassieke optimale demping. Twee grenzen
bepalen het venster voor $L$ (figuur~\ref{fig:venster}):
\begin{itemize}
\item \emph{bovengrens}: in de krapste bocht (straal $R$) moet de lijn onder de balk blijven,
  $L^2/(2R) \le e_{\text{bereik}}$, dus $L \le \sqrt{2Re_{\text{bereik}}}$; bij $R = \LijnRkrap$~cm en
  $e_{\text{bereik}} = \LijnEbereik$~mm is dat \LijnLmax~mm;
\item \emph{ondergrens}: de lus mag niet sneller willen reageren dan motor en bemonstering toelaten.
  Met de totale vertraging $T_d = \tau_m + T_s/2 = \LijnTd$~ms en de vuistregel $\omega_n T_d \le 0{,}3$
  wordt $L \ge \sqrt2\, v T_d / 0{,}3$, bij 0,3~m/s \LijnLmin~mm.
\end{itemize}
Bij 0,3~m/s sluiten die grenzen elkaar uit: in krappe bochten moet de auto langzamer. Dat doet de
snelheidswet $v = \max\!\bigl(v_{\min},\, v_{\max}(1 - k_v|\hat e|/e_{\text{bereik}})\bigr)$.
Daarnaast begrenst de motor zelf de bochtsnelheid: het buitenwiel rijdt $v(1 + b/2R) \le v_0$, dus
$v \le v_0/(1 + b/2R) = \LijnVbocht$~m/s bij $R = \LijnRkrap$~cm.
Het simulatie-optimum ($L = \LijnBestL$~mm) ligt onder de vuistregel-ondergrens: de lus is minder
gedempt dan $\zeta = 1/\sqrt2$ en slingert licht om de lijn (ongeveer $\pm$7~mm,
figuur~\ref{fig:tijd}). De kostfunctie accepteert dat in ruil voor snelheid.

\begin{figure}[H]
\centering

\caption{Venster voor de look-ahead $L$: boven de blauwe lijn raakt de auto de lijn kwijt in een bocht
met straal $R$, onder een stippellijn reageert de lus te snel voor motor en bemonstering.}
\label{fig:venster}
\end{figure}

\subsection{Optimalisatie}
Kost per rit (\texttt{lijn\_kost.m}), lager is beter:
\begin{equation}
J = \frac{T v_0}{L_{\text{baan}}}
+ \lambda_e \max\!\left(0, \frac{e_{\max}}{e_{\text{toel}}} - 1\right)
+ \lambda_k f_{\text{kwijt}} + \lambda_j\, j
\label{eq:jlijn}
\end{equation}
met de genormaliseerde rondetijd ($=1$: hele ronde op volle motorsnelheid), een straf als de grootste
afwijking van de aandrijfas boven $e_{\text{toel}} = 30$~mm komt (F3.1 zegt 50~mm; 20~mm marge voor de
verschillen tussen simulatie en werkelijkheid), de tijdfractie dat de lijn kwijt is en het gejitter van
de PWM. Een mislukte rit kost $10 + 10\,(1-\text{voortgang})$. Per sensoropstelling ($L \times s$, vier
sensoren) worden eerst de vijf regelaarparameters $K_p, K_d, \tau_d, v_{\max}, k_v$ geoptimaliseerd
(\LijnNkand\ kandidaten, vier trainingsbanen, waaronder een met haakse bochten); pas daarna worden
de opstellingen vergeleken. Een opstelling beoordelen met een slecht afgestelde regelaar zegt niets
over de opstelling.

\begin{figure}[H]
\centering

\caption{Beste haalbare prestatie per sensoropstelling, elk met een eigen geoptimaliseerde regelaar.
Grijs met $\times$: haalt de eis met marge niet. Tussen haken: het optimum.}
\label{fig:kaart}
\end{figure}

\subsection{Resultaten}
Het optimum ligt op $L = \LijnBestL$~mm en $s = \LijnBestSteek$~mm, met
$K_p = \LijnBestKp$~rad/s per m, $K_d = \LijnBestKd$~rad/s per m/s, een D-filter van
$\tau_d = \LijnBestTaud$~ms, $v_{\max} = \LijnBestVmax$~m/s en $k_v = \LijnBestKv$. Tabel~\ref{tab:val}
toetst vier instellingen op \LijnNtest\ banen die de optimizer niet kende, elk meerdere keren met andere
afwijkingen (\LijnNrun\ ritten per instelling).

\begin{table}[H]
\centering\footnotesize
\input{resultaten/tabel_lijn_validatie}
\caption{Validatie. ``Huidige sim'' is de regelaar uit \texttt{RobotCar\_LineFollower\_Sim.m}
($K_p = 28$ per gewichtseenheid $\approx \LijnBaseKp$~rad/s per m, 50~Hz) op het realistische motormodel.
Let op: in dat script staat \texttt{omega = -(Kp*pos\_error + Kd*d\_error)} terwijl \texttt{pos\_error}
positief is als de lijn links ligt; zo stuurt de auto van de lijn af (headless nagerekend: na 0,1~s is
hij de lijn kwijt en rijdt hij rondjes). Voor deze vergelijking is het teken omgedraaid.}
\label{tab:val}
\end{table}

Opvallend: de huidige regelaar komt wel rond, maar zijn $K_p$ is zo groot dat elke sensor die omslaat
de wielen van vol links naar vol rechts stuurt (gejitter \LijnBaseJit\ PWM-fractie per stap tegen
\LijnBestJit\ voor het optimum): slecht voor tandwielkast en accu, en traag omdat de auto
slingert. De analytische $K^*$ uit \eqref{eq:kster} alleen is stabiel maar voorzichtig; de optimizer
vindt een hogere snelheid met een snelheidswet die in de bochten terugschakelt.

De sensoropstelling zelf maakt binnen een breed gebied weinig uit: in figuur~\ref{fig:kaart} liggen alle
opstellingen met $L$ tussen 45 en 80~mm en een steek van 8 tot 15~mm binnen 5~\% van elkaar. Pas bij een
steek van 18~mm of meer, een balk vlak bij de as (30~mm) of ver ervoor (100~mm en meer) wordt het
duidelijk slechter. De winst van \LijnBaseTpar\ naar \LijnBestTpar~s komt dan ook vrijwel helemaal uit
de regelaar: met de huidige sensorplaatsing en een geoptimaliseerde regelaar is het resultaat even goed
(tabel~\ref{tab:val}). De huidige regelaar komt wel rond, maar wijkt op de testbanen tot
\LijnBaseEmax~mm af en haalt F3.1 dus niet.

\begin{table}[H]
\centering\footnotesize
\input{resultaten/tabel_lijn_varianten}
\caption{Aantal sensoren en analoog uitlezen, elk met een eigen geoptimaliseerde regelaar.}
\label{tab:var}
\end{table}

\begin{figure}[H]
\centering

\caption{Huidige sim tegen optimum op een parcours met haakse bochten.}
\label{fig:tijd}
\end{figure}

\begin{figure}[H]
\centering

\caption{Robuustheid van het optimum op de testbanen. Links: tapebreedte (T9.1 staat 1 tot 2~cm toe).
Bij 10~mm is de steek groter dan de tape, zodat volgens \eqref{eq:steek} gaten ontstaan; de auto komt
toch rond ($e_{\max} = \LijnTapeTienE$~mm, \LijnTapeTienOk~\% voltooid), omdat de lijn door de
look-ahead en de lichtvlek zelden lang in een gat blijft. Midden: regellusfrequentie. Rechts: breedte
van de lichtvlek (hoogte van de sensor). $e_{\max}$ is een slechtste-gevalwaarde over een beperkt aantal
ritten en springt daardoor; geen van de drie laat een duidelijke trend zien.}
\label{fig:rob}
\end{figure}

\subsection{Vertaling naar de Arduino-code}
De regelaar werkt in SI-eenheden; op de ATmega328P (geen FPU) wordt het integerwerk (Wescott 2000).
Per millimeter lijnfout verschuift elk wiel
$\Delta\text{PWM} = K_p \cdot 10^{-3} \cdot \tfrac{b}{2} / v_0 \cdot 255 \approx \LijnBestPwmMm$
PWM-stappen (links erbij, rechts eraf). De D-term op de gemeten positie door een eerste-ordefilter:
$D_k = D_{k-1} + \frac{T_s}{\tau_d + T_s}\bigl((\hat e_k - \hat e_{k-1})/T_s - D_{k-1}\bigr)$; reken
$\hat e$ in hele millimeters en schaal de versterkingen met een macht van 2, dan blijft alles in
\texttt{int16\_t}.

% =====================================================================
\section{Simulatie 2: obstakels herkennen en ontwijken (F2)}

\subsection{Model van de HC-SR04}
De module meet de looptijd van de eerste echo die terugkomt:
\begin{equation}
d = \frac{c\, t_{\text{echo}}}{2},\qquad c = 331{,}3 + 0{,}606\,T~\text{m/s}\quad (T\text{ in °C})
\label{eq:echo}
\end{equation}
In de simulatie is de bundel een waaier van stralen over $[-\beta, \beta]$. Een straal telt alleen als
het vlak dat hij raakt hem terugkaatst: de invalshoek (tussen straal en normaal) moet kleiner zijn dan
$\gamma_{\max}$. Een glad vlak dat te schuin staat kaatst de puls weg, als een spiegel
(Leonard \& Durrant-Whyte 1992); kistranden en binnenhoeken geven wel altijd een zwakke echo. Daarna
komen ruis ($\sigma = 3$~mm), afronding op hele centimeters zoals de Arduino-code doet, 0--4~\% gemiste
echo's, en de timing: een puls om de $T_{\text{meas}} \ge 60$~ms (datablad), het resultaat
$2d/c$ later, bij geen echo pas na de time-out van 38~ms. Twee of drie sensoren vuren om de beurt,
anders horen ze elkaars echo.

\subsection{Remweg en de hoogste snelheid die F2.3 haalt}
Van ``obstakel dichter dan $d_{\text{stop}}$'' tot ``remmen'' zit in het slechtste geval
\begin{equation}
t_{\text{lat}} = n\,T_{\text{meas}}\Bigl(1 + \frac{N_f - 1}{2}\Bigr) + \frac{2d}{c} + \frac{1}{f_s}
\label{eq:tlat}
\end{equation}
($n$ sensoren om de beurt; een mediaanfilter over $N_f$ metingen heeft $(N_f+1)/2$ lage metingen nodig).
Voor één sensor, 60~ms en $N_f = 3$ is dat \ObstTlatEen~ms, voor drie sensoren \ObstTlatDrie~ms. De
remweg hangt af van hoe de L298N remt:
\begin{equation}
s_{\text{rem}} =
\begin{cases}
v\,\tau_m & \text{kortsluitrem (IN1 = IN2, EN hoog)}\\
v\,\tau_m - v_0\tau_m \ln(1 + v/v_0) & \text{tegenstroom, gedurende } t^* = \tau_m\ln(1 + v/v_0)\\
v^2 / (2 a_{\text{rol}}) & \text{uitrollen (EN laag)}
\end{cases}
\label{eq:rem}
\end{equation}
Bij 0,3~m/s is dat \ObstSremKort, \ObstSremTegen\ en \ObstSremRol~cm. F2.3 eist remmen vanaf 20~cm
met 2~cm speling, dus $v\,t_{\text{lat}} + s_{\text{rem}}(v) \le 18$~cm. Met de kortsluitrem geeft dat
$v_{\max} = \ObstVmaxEen$~m/s voor één sensor en \ObstVmaxDrie~m/s voor drie; laat de code de motoren
uitrollen (\texttt{analogWrite(EN, 0)}), dan nog maar \ObstVmaxRol~m/s (figuur~\ref{fig:rem}).

\begin{figure}[H]
\centering

\caption{(a) Remweg per remmethode en reactieweg. (b) Hoogste snelheid waarbij de auto volgens F2.3
op tijd stilstaat, als functie van de meetperiode en de filterlengte.}
\label{fig:rem}
\end{figure}

\subsection{Welk deel van de auto ziet de sonar?}
Een obstakel op zijafstand $y$ ligt in de bundel van één sensor recht vooruit zolang $x \ge |y|/\tan\beta$.
Nadert de auto, dan valt het er juist \emph{uit}. Op de stopafstand is de beschermde breedte
\begin{equation}
B_{\text{besch}} = 2\, d_{\text{stop}} \tan\beta
\qquad\text{en de hele breedte } B \text{ vraagt}\qquad
d_{\text{stop}} \ge \frac{B/2}{\tan\beta}
\label{eq:besch}
\end{equation}
Bij $d_{\text{stop}} = 22$~cm is $B_{\text{besch}} = \ObstBbeschA$~mm ($\beta = 7{,}5^\circ$) tot
\ObstBbeschB~mm ($\beta = 15^\circ$) van de 143~mm; de hele breedte zien vraagt stoppen op
\ObstDnodigA\ resp.\ \ObstDnodigB~cm, en dat botst met F2.1 (doorrijden zolang 30~cm vrij is). Een
poot of de hoek van een kist die 4--7~cm naast het midden staat, raakt dus de neus zonder ooit gezien
te zijn. Voor meer sensoren geldt: een punt $(x, y)$ wordt door sensor $i$ op $(x_i, y_i)$ met
kijkrichting $\alpha_i$ gezien als
\begin{equation}
\bigl|\operatorname{atan2}(y - y_i,\; x - x_i) - \alpha_i\bigr| \le \beta
\label{eq:kegel}
\end{equation}
Figuur~\ref{fig:dek}a telt voor elke opstelling welk deel van de breedte ergens tussen 5 en 22~cm voor de
sensor in een bundel valt. Twee sensoren ``scheel'' (de linker kijkt naar rechts, \texttt{kruis2}) dekken
het meest: bij elke $\alpha$ tussen \ObstAlfaKruisLo° en \ObstAlfaKruisHi° valt \ObstDekKruisOpt~\% van
de breedte in een bundel, tegen \ObstDekRechtA--\ObstDekRechtB~\% voor één sensor. Twee naar buiten gedraaide sensoren
(\texttt{uit2}) laten het midden open.

\begin{figure}[H]
\centering

\caption{(a) Gedekte autobreedte als functie van de uitdraaihoek, uit \eqref{eq:kegel}. (b) Bundels van
het simulatie-optimum ($\beta = 7{,}5^\circ$ en $15^\circ$); stippellijnen: rijstrook.}
\label{fig:dek}
\end{figure}

\subsection{Rechtdoor rijden, draaien en de achterkant}
\textbf{Drift (F2.1).} Draait het rechterwiel een fractie $\delta$ sneller dan gevraagd en het linker
$\delta$ langzamer, dan rijdt de auto een cirkel met straal $b/(2\delta)$ en wijkt hij over een afstand
$s$ af met
\begin{equation}
y(s) = \frac{\delta\, s^2}{b}
\qquad\Longrightarrow\qquad
\delta \le \frac{y_{\max}\, b}{s^2} = \frac{0{,}40 \cdot 0{,}108}{2^2} = \ObstDeltaMax~\%
\label{eq:drift}
\end{equation}
Zonder terugkoppeling moeten de motoren dus tot op ongeveer 1~\% gelijk lopen; ongekalibreerde
TT-motoren ($\pm$5~\%) rijden een cirkel van \ObstRcirkel~m. Een trimfactor per motor (afregelen op een
rechte lijn) of encoders zijn nodig. Vanaf hier is aangenomen dat de motoren op 1~\% na zijn
gekalibreerd.

\textbf{Draaien zonder encoders.} Zonder encoders weet de regelaar zijn draaihoek alleen uit tijd maal
gevraagde draaisnelheid. Bij 2~rad/s is de PWM-fractie per wiel $u = \ObstDraaiU$~\%; na
dode-zonecompensatie met een geschatte $\hat u_{dz}$ is de echte draaisnelheid
\begin{equation}
\frac{\omega_{\text{echt}}}{\omega_{\text{gevraagd}}} = \frac{u' - u_{dz}}{(1 - u_{dz})\,u},\qquad
u' = \hat u_{dz} + (1 - \hat u_{dz})\,u
\label{eq:draaifout}
\end{equation}
wat voor $u_{dz}$ tussen 22 en 10~\% een fout van \ObstDraaiMin\ tot $+$\ObstDraaiMax~\% geeft.
``Kijk links en rechts en draai terug naar het beste gat'' mist daardoor tientallen graden; ``draai tot
de sonar vrij meldt'' niet, want die sluit de lus via de sensor. Met encoders van 20 pulsen per
omwenteling is de hoekstap $2\pi r/(N b) = \ObstEncStap^\circ$.

\textbf{Draaisnelheid.} Om geen gat te missen mag de auto tussen twee metingen van dezelfde sensor niet
verder draaien dan de bundelbreedte: $\omega\, n\, T_{\text{meas}} \le 2\beta$, dus
$\omega \le \ObstWmaxEen$~rad/s voor één sensor en \ObstWmaxDrie~rad/s voor drie.

\textbf{Achterkant.} Op de plaats draaien zwiept de achterkant rond met straal
$R = \sqrt{a^2 + (B/2)^2} = \ObstRzwaai$~mm ($a$ = overhang achter de as), veel meer dan de neus
(\ObstRvoor~mm). De sonar ziet dat niet. Met een overhang van 90~mm (de frame-analyse) wordt dat
\ObstRzwaaiKort~mm; in de simulatie gaat het botsingsvrije percentage daarmee van \ObstBestPv\ naar
\ObstKortPv~\%. Een input voor het verbeterde 3D-model.

\subsection{Gedrag en optimalisatie}
De toestandsmachine volgt F2.1--F2.4: \textsc{rijden} (vol door zolang de rijstrook $\ge d_{\text{slow}}$
vrij is, daarna afbouwen tot $v_{\text{kruip}}$), \textsc{remmen} onder $d_{\text{stop}}$,
\textsc{kiezen} (op de plaats draaien tot er 60~cm vrij is, of eerst naar beide kanten kijken) en zo
nodig \textsc{achteruit} (max.\ 30~cm). Drie ``slimme'' regels die de simulatie nodig bleek te hebben:
\begin{itemize}
\item \emph{rijstrook-logica}: een echo telt alleen als hij binnen de breedte van de auto kan liggen,
  zodat een schuine sensor niet stopt voor een muur waar de auto langs rijdt;
\item \emph{geen echo is niet vrij}: tijdens het kiezen telt een time-out niet als vrije ruimte, want dat
  is precies wat een schuine muur geeft;
\item \emph{doordraaien}: na de eerste vrije meting nog $\varphi_{\text{extra}}$ verder draaien, zodat de
  auto niet vertrekt langs de rand van het gat.
\end{itemize}
Per opstelling (\texttt{recht}, \texttt{kruis2}, \texttt{uit2}, \texttt{drie}), met en zonder encoders,
zoekt de optimizer 13 parameters (\texttt{obst\_zet.m}) af in \ObstNtrain\ arena's, met kost
\begin{equation}
J = f_{\text{botsing}} + 0{,}25\left(1 - \frac{\bar s}{v_0\, T_{\text{rit}}}\right) + 0{,}1\, f_{\text{eis}}
\label{eq:jobst}
\end{equation}
(fractie ritten met een botsing, gemiddeld afgelegde afstand, fractie stops die F2.3 of F2.4 schendt).
Daarna rijdt elk optimum in \ObstNval\ nieuwe arena's van twee soorten: \emph{rommel} (kisten onder
willekeurige hoek en dunne poten) en \emph{rustig} (alleen kisten van minstens 15~cm).

\subsection{Resultaten}
\begin{table}[H]
\centering\footnotesize
\input{resultaten/tabel_obst_opstellingen}
\caption{Validatie per opstelling, elk met eigen geoptimaliseerd gedrag. ``Test gehaald'' is de kans
dat minstens 2 van 3 ritten botsingsvrij zijn: $3p^2 - 2p^3$.}
\label{tab:obst}
\end{table}

Op de trainingsarena's scoorde \texttt{\ObstBestOpst} \ObstBestEnc\ het best, met uitdraaihoek \ObstBestAlfa°,
kruissnelheid \ObstBestV~m/s, stoppen op \ObstBestDstop~cm en afbouwen vanaf \ObstBestDslow~cm, een
puls om de \ObstBestTmeas~ms, mediaanfilter $N_f = \ObstBestNf$, draaien met \ObstBestWdraai~rad/s
(strategie \emph{\ObstBestStrat}, doordraaien \ObstBestExtra°), remmen met \emph{\ObstBestRem} en
``geen echo is niet vrij'': \ObstBestEcho. In de validatie deed dezelfde opstelling \emph{zonder}
encoders het beter (\ObstBestZonderPv\ tegen \ObstBestPv~\%). Met 16 trainingsarena's is de keuze van de
optimizer tussen twee zo dicht bij elkaar liggende varianten dus niet betrouwbaar. Wat wel vaststaat:
\texttt{kruis2} is de enige opstelling die ruim boven de andere uitkomt, en één sonar recht vooruit haalt
vrijwel nooit een rit van 2~minuten. De optimizer koos een lage kruissnelheid en een grote uitdraaihoek
(\ObstBestAlfa°, buiten het plateau van figuur~\ref{fig:dek}a): hij ruilt dekking van de hoeken van de
auto in voor het zien van muren onder een scherende hoek. Alle instellingen per opstelling staan in
\texttt{resultaten/obst\_optimum.mat} (variabele \texttt{RES}).

\begin{figure}[H]
\centering

\caption{(a) Botsingsvrije ritten per opstelling in nieuwe arena's. (b) Van kans per rit naar kans dat de
F2-test slaagt.}
\label{fig:obstres}
\end{figure}

\begin{figure}[H]
\centering
\begin{minipage}[t]{0.47\textwidth}\centering

\caption{De uitkomst hangt sterk af van $\gamma_{\max}$: van \ObstGamDertig~\% bij 30° tot
\ObstGamZestig~\% bij 60° voor het optimum.}
\label{fig:gamma}
\end{minipage}\hfill
\begin{minipage}[t]{0.50\textwidth}\centering

\caption{Een rit van het optimum; kleur = toestand.}
\label{fig:rit}
\end{minipage}
\end{figure}

% =====================================================================
\section{Wat dit betekent voor het ontwerp}
\begin{enumerate}[leftmargin=6mm]
\item \textbf{Lijnsensor}: vier kopjes op een steek van \LijnBestSteek~mm, \LijnBestL~mm voor de
  aandrijfas; alles tussen 45 en 80~mm en een steek van 8 tot 15~mm is vrijwel even goed. De losse
  kopjes van een 4-kanaals tracker kun je vrij plaatsen. Wordt de tape 10~mm, zet de steek dan op
  $w/1{,}5 \approx 7$~mm.
\item \textbf{Lijnregelaar}: dit is waar de winst zit. PD met gefilterde D-term op 200~Hz, instellingen
  hierboven; begin op de echte auto met deze waarden en stel alleen $K_p$ en $v_{\max}$ bij. Wie
  voorzichtig wil beginnen: de analytische $K^* = 2v/L^2$ geeft de kleinste afwijking (12~mm), maar is
  anderhalf keer zo traag.
\item \textbf{Sonar}: gebruik beide bestelde HC-SR04's voor F2, gekruist: de linker kijkt
  \ObstAlfaKruisLo--\ObstAlfaKruisHi° naar rechts en omgekeerd (de simulatie koos \ObstBestAlfa°).
  Laat ze om de beurt vuren.
\item \textbf{Motoren}: kalibreer een trimfactor per motor (F2.1 vraagt $\le$\,\ObstDeltaMax~\%
  verschil). Encoders gaven in deze simulatie geen aantoonbare winst voor F2 (tabel~\ref{tab:obst}),
  maar maken draaien over een vaste hoek wel nauwkeurig.
\item \textbf{Remmen}: kortsluitrem (IN1 = IN2 met EN hoog), nooit uitrollen.
\item \textbf{3D-model}: maak de overhang achter de as korter of de achterkant rond (zwaaistraal).
\end{enumerate}

\section{Wat eerst gemeten moet worden}
Een simulatie is zo goed als de getallen die erin gaan (Mouret \& Chatzilygeroudis 2017). De getallen
met [AANN] in \texttt{qdat\_parameters.m} zijn schattingen; de eerste vier zijn het belangrijkst:
\begin{enumerate}[leftmargin=6mm]
\item $\gamma_{\max}$: zet de auto op 30~cm voor de muur en een kist, draai hem in stappen van 5° en noteer
  tot welke hoek de HC-SR04 nog een echo geeft. Dit getal bepaalt de uitkomst van F2 het meest
  (figuur~\ref{fig:gamma}).
\item Dode zone en $v_0$: laat de PWM langzaam oplopen tot de wielen draaien; meet de snelheid bij
  PWM 255 over 2~m.
\item $\tau_m$ en remweg: film een noodstop vanaf 0,3~m/s naast een meetlat; vergelijk met
  \eqref{eq:rem}.
\item Lichtvlek $\sigma$: schuif een sensorkopje dwars over de tape en log de analoge waarde; pas
  \eqref{eq:dekking} erop.
\end{enumerate}
Het eigenlijke resultaat van dit onderzoek is dan het verschil tussen simulatie en werkelijkheid in
meetbare eenheden: rijd hetzelfde parcours met dezelfde instellingen en vergelijk rondetijd en
$e_{\max}$ met tabel~\ref{tab:val}.

\section{Bestanden}
\begin{center}\footnotesize
\begin{tabular}{@{}ll@{}}
\toprule
bestand & functie \\
\midrule
\texttt{qdat\_parameters.m} & alle maten en aannames, met bron \\
\texttt{onderzoek\_lijnvolgen.m} & simulatie 1: kaart, varianten, validatie, figuren (\LijnDuur~min) \\
\texttt{onderzoek\_obstakels.m} & simulatie 2: analyse, optimalisatie, validatie, figuren (\ObstDuur~min) \\
\texttt{demo\_lijnvolgen.m}, \texttt{demo\_obstakels.m} & 3D-weergave van een rit, optioneel als MP4 \\
\texttt{model/} & rekenkern: voertuig, sensoren, banen, arena's, beide simulaties, 3D-model \\
\texttt{optimalisatie/} & kostfuncties, random search, validatie \\
\texttt{resultaten/} & figuren en \texttt{.tex}-bestanden met de getallen voor dit document \\
\bottomrule
\end{tabular}
\end{center}

\begin{thebibliography}{9}\footnotesize
\setlength{\itemsep}{0pt}
\bibitem{bra} V.~Braitenberg, \emph{Vehicles: Experiments in Synthetic Psychology}. MIT Press, 1984.
\bibitem{han} N.~Hansen, ``The CMA Evolution Strategy: A Tutorial'', arXiv:1604.00772, 2016.
\bibitem{jak} N.~Jakobi, P.~Husbands, I.~Harvey, ``Noise and the Reality Gap'', ECAL 1995, LNCS 929, pp.~704--720.
\bibitem{leo} J.\,J.~Leonard, H.\,F.~Durrant-Whyte, \emph{Directed Sonar Sensing for Mobile Robot Navigation}. Kluwer, 1992.
\bibitem{mou} J.-B.~Mouret, K.~Chatzilygeroudis, ``20 Years of Reality Gap'', GECCO '17 Companion, pp.~1121--1124.
\bibitem{sie} R.~Siegwart, I.\,R.~Nourbakhsh, D.~Scaramuzza, \emph{Introduction to Autonomous Mobile Robots}, 2e dr. MIT Press, 2011.
\bibitem{tob} J.~Tobin e.a., ``Domain Randomization for Transferring Deep Neural Networks from Simulation to the Real World'', IROS 2017, pp.~23--30.
\bibitem{wes} T.~Wescott, ``PID Without a PhD'', \emph{Embedded Systems Programming}, okt.~2000.
\end{thebibliography}

\end{document}

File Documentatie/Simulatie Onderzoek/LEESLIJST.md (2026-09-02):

# Leeslijst — simulatie + automatisch afstellen van de lijnvolger

Zij-onderzoek naast Project 1 NL (Robot-car). Valt **buiten** de gestelde
projecteisen; raakt alleen F3.1 ("een lijn kunnen volgen").

Alle gegevens hieronder zijn nagekeken bij de uitgever, arXiv, IEEE, ACM of ASME
(september 2026). PDF's kun je in `Papers/` zetten.

Legenda: **[gratis]** = vrij te downloaden · **[HAN]** = achter betaalmuur, via
de HAN-bibliotheek waarschijnlijk wel binnen te halen.

---

## Blok A — Waarom simulaties liegen

Dit blok beschrijft precies het risico van jouw plan: een regelaar die in
simulatie prachtig rondrijdt en op de echte vloer meteen de bocht uit vliegt.
Als je maar drie dingen leest, lees dan hieruit.

**A1. Mouret & Chatzilygeroudis (2017) — "20 Years of Reality Gap: a few
Thoughts about Simulators in Evolutionary Robotics"** **[gratis]**
GECCO '17 Companion, ACM, pp. 1121–1124 · DOI `10.1145/3067695.3082052`
PDF: http://www.cmap.polytechnique.fr/~nikolaus.hansen/proceedings/2017/GECCO/companion/companion_files/wksp147s1-file1.pdf

> Vier pagina's, twintig jaar ervaring, nuchter opgeschreven. Hoogste
> informatiedichtheid van de hele lijst. **Begin hier.**

**A2. Jakobi, Husbands & Harvey (1995) — "Noise and the Reality Gap: The Use of
Simulation in Evolutionary Robotics"** **[HAN]**
ECAL 1995, LNCS 929, Springer, pp. 704–720 · DOI `10.1007/3-540-59496-5_337`

> Het startpunt van het vakgebied; introduceert de term *reality gap*.
> Meenemen: **voeg bewust ruis toe** aan je gesimuleerde sensoren en motoren.
> Een regelaar die alleen werkt bij perfecte metingen is waardeloos. Goedkoopste
> en belangrijkste ingreep in je hele opzet.

**A3. Jakobi (1997) — "Evolutionary Robotics and the Radical
Envelope-of-Noise Hypothesis"** **[HAN]**
Adaptive Behavior 6(2), pp. 325–368 · DOI `10.1177/105971239700600205`

> Werkt A2 uit tot een recept: bepaal wat je écht vertrouwt aan je simulatie, en
> varieer al het andere zo hard dat de optimizer er niet op kan leunen.
> Voor jou: vertrouwde basis ≈ {wielbasis, wieldiameter, sensorafstanden} —
> dingen die je met een schuifmaat nameet. Wrijving, motor-deadband,
> tapereflectie en batterijspanning laat je juist willekeurig variëren.

**A4. Tobin et al. (2017) — "Domain Randomization for Transferring Deep Neural
Networks from Simulation to the Real World"** **[gratis]**
IROS 2017, IEEE, pp. 23–30 · arXiv:`1703.06907` · DOI `10.1109/IROS.2017.8202133`
https://arxiv.org/abs/1703.06907

> Neem het *idee* over, niet de methode — zij trainen neurale netwerken op
> beelden, jij tunet vier getallen. Vertaling: optimaliseer niet op één baan,
> maar op honderd willekeurige banen met per run andere wrijving, deadband en
> accuspanning. Wat daar gemiddeld goed uit komt, overleeft de echte vloer.

**A5. Muratore et al. (2022) — "Robot Learning From Randomized Simulations:
A Review"** **[gratis, open access]**
Frontiers in Robotics and AI 9:799893 · DOI `10.3389/frobt.2022.799893`
https://arxiv.org/abs/2111.00956

> Overzichtsartikel. Vooral bruikbaar als bronnenkaart. Grote delen gaan over
> deep reinforcement learning en zijn voor jou niet relevant — lees selectief.

---

## Blok B — De regelaar zelf

**B1. Wescott (2000) — "PID Without a PhD"** **[gratis]**
Embedded Systems Programming, oktober 2000
https://www.wescottdesign.com/articles/pid/pidWithoutAPhd.pdf

> Klassieker, geschreven voor precies jouw situatie: PID in C op een kleine
> microcontroller, zonder regeltechniek vooraf. Windup, afgeleide op de meting
> i.p.v. op de fout, vaste-komma-rekenwerk.
>
> **Belangrijkste detail voor je simulatie:** de ATmega328P heeft geen FPU, dus
> je regelaar wordt integerwerk. Simuleer dan ook de *integer*-versie inclusief
> afkapping — anders transfereren je getunede waarden niet en heb je voor niets
> gerekend.

**B2. Ziegler & Nichols (1942) — "Optimum Settings for Automatic Controllers"**
**[HAN]**
Transactions of the ASME 64(8), pp. 759–765 · DOI `10.1115/1.4019264`

> Je **referentiepunt**. "Onze optimizer vond goede waarden" is een lege
> bewering zonder vergelijking. Met een Ziegler–Nichols-afstelling ernaast wordt
> het een meetbaar resultaat — en dat is wat een tutor onder "onderbouwing van
> ontwerpkeuzes" wil zien.

---

## Blok C — Lijnvolgers concreet

**C1. Oguten & Kabas (2021) — "PID Controller Optimization for Low-cost Line
Follower Robots"** **[gratis]**
arXiv:`2111.04149` · https://arxiv.org/abs/2111.04149

> Het dichtst bij jouw project van alles hier: PID-optimalisatie voor een
> goedkope differentieel aangedreven lijnvolger met reflectiesensor en
> motordriver — dezelfde klasse hardware als de Robot-car. Inclusief publieke
> broncode.
>
> **Lees dit vóór je begint te bouwen.** Hun handmatige/heuristische aanpak is
> je ondergrens: komt jouw simulatie + optimizer daar niet overheen, dan is de
> extra complexiteit niet te verdedigen. Preprint, geen peer review — kritisch
> lezen.

**C2. Pakdaman & Sanaatiyan (2009) — "Design and Implementation of Line
Follower Robot"** **[HAN]**
ICCEE 2009, vol. 2, IEEE, pp. 585–590 · DOI `10.1109/ICCEE.2009.43`

> Ouderwets en juist daarom bruikbaar: complete bouwbeschrijving met een
> IR-sensorarray, inclusief de plaatsingsproblemen. De geometrie van je
> sensorbalk (onderlinge afstand, afstand tot de wielas) bepaalt hoe je je
> positiefout berekent — die maten moeten in de simulatie kloppen met de echte
> auto.

---

## Blok D — Optimalisatie en kinematica

**D1. Hansen (2016) — "The CMA Evolution Strategy: A Tutorial"** **[gratis]**
arXiv:`1604.00772` · https://arxiv.org/abs/1604.00772

> **Nog niet toepassen.** Begin met random search over vier parameters — twintig
> regels code, werkt in zo'n kleine zoekruimte verrassend goed. Pak dit er pas
> bij als je aantoonbaar tegen de grenzen daarvan aanloopt. Zo niet: noem het in
> je rapport als afweging (overwogen, niet nodig gebleken). Dat leest beter dan
> een ongebruikt algoritme.

**D2. Siegwart, Nourbakhsh & Scaramuzza (2011) — *Introduction to Autonomous
Mobile Robots*, 2e druk, MIT Press** **[HAN]**

> Hoofdstuk 3 geeft het kinematisch model van een differentieel aangedreven
> robot — de kern van je simulator. In essentie: `v = (v_r + v_l) / 2` en
> `ω = (v_r − v_l) / L`, met `L` de wielbasis. Meer heb je voor een 2D-simulatie
> niet nodig. Check de HAN-bibliotheek op een digitale licentie voor je dit boek
> koopt.

**D3. Dudek & Jenkin (2010) — *Computational Principles of Mobile Robotics*,
2e druk, Cambridge University Press** **[HAN]**

> Alternatief voor D2, met meer aandacht voor odometrie en foutenopbouw.
> Optioneel — pak D2 óf D3, niet allebei.

---

## Leesvolgorde

1. **A1** — vier pagina's, meteen het hele probleem helder
2. **C1** — jouw project, al eens gedaan door iemand anders
3. **B1** — hoe je de regelaar fatsoenlijk in C schrijft
4. **D2 hoofdstuk 3** — de vergelijkingen voor je simulator
5. **A2** en **A3** — pas lezen als de simulator draait en de eerste resultaten
   verdacht goed zijn. Dat moment komt.
6. De rest naar behoefte.

---

## Vragen om tijdens het lezen bij te houden

- Welke grootheden ga ik aan de echte auto **meten** i.p.v. schatten?
  (PWM→toerental-curve, deadband, wielbasis, wieldiameter, sensorafstanden,
  sensorrespons op zwart tape op linoleum.)
- Met welke tijdstap draait de simulatie, en komt die overeen met de echte
  regellus-frequentie op de ATmega328P?
- Hoe genereer ik willekeurige banen die lijken op de echte baan in de gang van
  R29 — welke bochtstralen komen daar voor?
- Wat is mijn fitness-functie precies? Rondetijd alleen is niet genoeg; er moet
  straf op lijnverlies en op oscillatie.
- **Hoe groot is het verschil tussen simulatie en werkelijkheid, in meetbare
  eenheden?** Dit is het eigenlijke resultaat van het onderzoek — interessanter
  dan de getunede waarden zelf, en het enige deel dat een echte onderzoeksvraag
  beantwoordt.

---

`referenties.bib` in `Literatuur/` bevat dezelfde bronnen als BibTeX, voor als
je hier later in het productrapport naar verwijst. Weggooien mag.

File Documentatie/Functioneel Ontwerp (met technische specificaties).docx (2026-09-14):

Functioneel Ontwerp

Specificatie van de systeemfuncties, use-cases en gebruikersvereisten

Auteurs: | Tygo Poodt (2187406), Nathan Heuker of Hoek (2176586), Mohammed Özdemir (2172114), Floris Sevink (2186617), Milan Veulings (2190942), Mathijs Tijans (2192954)
Schoolbegeleider: | Michel Lennard De Boer – Han University of Applied Sciences
Opdrachtgever: | Peter Bijl – Han University of Applied Sciences
Bedrijfsnaam: | Q-Dat Systems – Groep 5
Versie: | V1.1
Datum: | 11-09-2026

Versiebeheer

Versienummer | Datum | Aanpassing
1.0 | 4-9-2026 | Tygo Poodt (2187406) – Template documentatie aangemaakt
1.1 | 11-9-2026 | Tygo Poodt (2187406) – Afspraken met de opdrachtgever verwerkt, technische specificaties en budgeteisen toegevoegd

# Inleiding

Voor je ligt het functioneel ontwerp voor ons robotauto-project op de HAN University of Applied Sciences. Wij voeren deze opdracht uit voor onze docent en opdrachtgever Peter Bijl, met Michel Lennard De Boer als onze schoolbegeleider.

Kort gezegd gaan we een slimme robotauto bouwen die op drie manieren kan werken. De auto moet helemaal zelfstandig door een parcours kunnen rijden zonder ergens tegenaan te botsen. Ook moet hij in een treintje achter een andere auto aan kunnen rijden over een lijn. Tot slot moet je hem gewoon zelf kunnen besturen met een remote control. Op een schermpje willen we handige info laten zien, zoals hoe vol de batterij nog is en in welke stand de auto staat.

Het doel van dit document is simpel: we willen laten zien hoe we dit voor ons zien en wat de auto straks allemaal moet kunnen. We kijken hier puur naar de werking en nog niet naar de precieze techniek of code daarachter. Zo weten Peter Bijl en wij vanaf het begin zeker dat we op één lijn zitten over wat we gaan opleveren.

De eerste versie van dit document bevatte nog open vragen aan de opdrachtgever. Die hebben we met Peter Bijl besproken; hij liet de meeste keuzes aan ons over. De antwoorden en onze keuzes zijn in deze versie verwerkt.

Eerst zetten we alle eisen op een rij met de MoSCoW-methode, zodat meteen duidelijk is wat er sowieso in moet zitten en wat eventueel later pas komt. Daarna maken we elke functie meetbaar (SMART), met per functie de gemaakte afspraken. We sluiten af met de technische specificaties en de budgeteisen.

# Functionele Eisen

In dit hoofdstuk staan alle functionele eisen van het project. Deze eisen beschrijven precies wat de robot-car en het besturingssysteem moeten kunnen en hoe het systeem zich gedraagt in verschillende situaties. De technische uitwerking (zoals de exacte code of printplaat) laten we hier buiten beschouwing; we focussen ons puur op de functies.

Tabel 1 – Functionele eisen

# | MoSCoW | Omschrijving

F1 | M | De robot-car moet kunnen rijden; zonder deze basisfunctie is er geen robot-car.
F1.1 | M | De robot-car rijdt vooruit en achteruit door beide motoren in dezelfde richting te laten draaien.
F1.2 | M | De robot-car draait links- en rechtsom om zijn eigen as, zodat hij bij vastlopen een andere route kan kiezen.
F1.3 | S | De robot-car rijdt in drie snelheidsstanden: langzaam (0,10 m/s), gemiddeld (0,20 m/s) en snel (0,30 m/s).
F1.4 | C | LED-richtingaanwijzers aan de achterkant geven aan welke kant de robot-car op draait.
F2 | M | In de mode Autonoom rijdt de robot-car zelfstandig door het testparcours: minimaal 2 minuten aaneengesloten zonder handmatig ingrijpen en zonder een obstakel te raken, in minimaal 2 van de 3 opeenvolgende testritten.
F2.1 | M | Zolang de robot-car recht vooruit binnen 30 cm geen obstakel meet, rijdt hij vooruit met een gemiddelde snelheid van minimaal 0,20 m/s en wijkt hij over een baan van 2 m maximaal 40 cm zijwaarts af.
F2.2 | M | De robot-car meet minimaal 5 keer per seconde de vrije ruimte recht vooruit en detecteert het referentieobstakel op elke afstand tussen 10 en 50 cm met een afwijking van maximaal 5 cm, in minimaal 4 van de 5 metingen.
F2.3 | M | Meet de robot-car recht vooruit een obstakel dichterbij dan 20 cm, dan begint hij binnen 500 ms te remmen en staat hij binnen 1,5 s stil met minimaal 2 cm ruimte tot het obstakel. Van 10 testsituaties mag er maximaal 1 misgaan.
F2.4 | M | Na het stoppen kiest de robot-car binnen 4 s zelfstandig een nieuwe richting: links- of rechtsom draaien, of maximaal 30 cm achteruitrijden. Hij rijdt verder zodra hij recht vooruit minimaal 60 cm vrije ruimte heeft.
F2.5 | M | De autonome mode kan via een commando worden gestart en gestopt, via het menu en via de USART. Na het startcommando wacht de robot-car minimaal 1 s voordat hij gaat rijden; na het stopcommando staat hij binnen 1 s stil.
F3 | M | De robot-car rijdt binnen 5 seconden na het inschakelen van slave-mode zelfstandig in slave-mode.
F3.1 | M | De robot-car volgt een lijn met een maximale afwijking van 5 cm ten opzichte van die lijn. Raakt hij de lijn kwijt, dan stopt hij.
F3.2 | M | Tijdens het volgen van de lijn volgt de robot-car ook een voorganger op een afstand tussen 10 en 50 cm, waarbij hij de lijn blijft volgen en achter de voorganger blijft rijden. De voorganger is een andere robot-car met een reflector aan de achterkant.
F3.3 | M | De robot-car staat binnen 2 seconden stil nadat de voorganger is gestopt en vertrekt pas weer wanneer de voorganger vertrekt.
F4 | M | De robot-car kan via een remote control worden bestuurd en reageert binnen 250 ms op een commando.
F4.1 | M | Via de remote control rijdt de robot-car vooruit en achteruit.
F4.2 | M | Via de remote control draait de robot-car links- en rechtsom om zijn eigen as.
F4.3 | S | Via de remote control is de snelheidsstand van de robot-car instelbaar.
F5 | M | De belangrijkste gegevens worden weergegeven op een display op de robot-car.
F5.1 | M | Het display geeft de rijrichting weer: vooruit, achteruit, links of rechts, samen met de snelheidsstand.
F5.2 | M | Het display geeft weer in welke mode de robot-car zich bevindt.
F5.3 | M | Het display geeft de totale gebruikstijd en de tijd in de huidige mode weer, in seconden.
F5.4 | C | Het display geeft het batterijniveau weer in procenten; onder 20 % knippert het als waarschuwing.
F6 | S | Via een menu op de robot-car kan de mode worden geselecteerd; bij het wisselen van mode stopt de auto eerst.
F6.1 | S | Via het menu kan de mode Autonoom worden geselecteerd, waarin de robot-car zelfstandig rijdt en obstakels ontwijkt volgens F2.
F6.2 | S | Via het menu kan de mode Slave worden geselecteerd, waarin de robot-car een lijn en een voorganger volgt volgens F3.
F6.3 | S | Via het menu kan de mode Remote control worden geselecteerd, waarin de robot-car met de remote control wordt bestuurd volgens F4.
F7 | C | De robot-car slaat de totale gebruikstijd elke minuut op en telt na het opnieuw opstarten verder vanaf de opgeslagen waarde. Via het menu kan de teller worden gereset.

# Smart Omschrijvingen

Hieronder is elke hoofdfunctie uitgewerkt volgens SMART. Onder Afspraken staat kort wat er met de opdrachtgever is besproken of wat wij hebben gekozen.

## F1 – De robot-car kan rijden

De robot-car moet zich in alle richtingen kunnen verplaatsen: vooruit, achteruit en draaien naar links of rechts. De snelheid is instelbaar en LED's laten zien welke kant hij op draait. Dit is de basis waar alle andere modes op verder bouwen.

Specifiek

Wie: de robot-car. Wat: vooruit en achteruit rijden, links- en rechtsom draaien, de snelheid regelen en de draairichting met LED's aangeven. Waar: op het testparcours in de projectruimte. Wanneer: zodra er via de remote control of via de actieve mode een rijcommando komt.

Meetbaar

De robot-car legt op commando minimaal 2 meter vooruit en achteruit af. Op commando draait hij een hele slag om zijn eigen as, naar links en naar rechts. De snelheid is in drie standen instelbaar: langzaam (0,10 m/s), gemiddeld (0,20 m/s) en snel (0,30 m/s). Draait hij naar links, dan knippert alleen de linker-LED (50 ms aan, 50 ms uit); draait hij naar rechts, dan alleen de rechter-LED. De LED gaat direct uit zodra het draaien stopt.

Acceptabel

Het wisselen van rijrichting doen we met een H-brug, dat kost alleen een kleine aanpassing in de code. Draaien om de eigen as is een kwestie van de linker- en rechterkant tegengesteld aansturen. De snelheid regelen we met PWM, dus zonder extra hardware. De LED's sluiten we aan op vrije pinnen van de microcontroller en koppelen we direct aan het draaicommando.

Realistisch

Zonder rijden en draaien loopt de auto vast en werkt geen enkele mode. Het is standaardfunctionaliteit die we volledig in software kunnen oplossen; de hardware zit al in het geleverde chassis. De variabele snelheid en de richtingaanwijzers zijn minder kritisch en staan daarom op Should en Could.

Tijdgebonden

De basisbesturing werkt voor de projectweek (week 45), zodat de andere modes daarop verder kunnen bouwen. We tonen het bij de demo van het tussenproduct in week 51 en opnieuw bij de eindoplevering in periode 2.

Afspraken

F1.2 – De auto draait om zijn eigen as (linker- en rechterkant in tegengestelde richting). Zo heeft hij de minste ruimte nodig.

F1.3 – Drie vaste standen: langzaam, gemiddeld en snel. De stand kan tijdens het rijden worden gewisseld.

F1.4 – Alleen richtingaanwijzers aan de achterkant.

## F2 – Autonoom rijden

In de mode Autonoom rijdt de robot-car zonder bestuurder door het testparcours. Hij meet de vrije ruimte recht vooruit, remt en stopt voor een obstakel, kiest daarna zelf een nieuwe richting en rijdt verder. De mode wordt gestart en gestopt met een commando via het menu of via de USART.

Specifiek

Wie: de robot-car, zonder bestuurder. Wat: zelfstandig rijden, obstakels op tijd zien en zelf uitwijken. Waar: op het testparcours in de projectruimte. Wanneer: zodra de autonome mode is gestart. Waarom: de opdrachtgever wil zien dat de auto zelfstandig rijdt zonder schade aan de auto of de omgeving.

Meetbaar

Minimaal 2 minuten aaneengesloten rijden zonder handmatig ingrijpen, geslaagd in 2 van de 3 testritten. Vooruit rijden met een gemiddelde snelheid van minimaal 0,20 m/s. Minimaal 5 metingen per seconde over een bereik van 10 tot 50 cm, met maximaal 5 cm afwijking. Remmen binnen 500 ms en stilstaan binnen 1,5 seconde met 2 cm ruimte over, waarbij maximaal 1 van de 10 pogingen misgaat. Binnen 4 seconden een nieuwe richting kiezen en verder rijden zodra er 60 cm vrije ruimte is.

Acceptabel

De eisen komen rechtstreeks uit de concepteisen: autonoom rijden, van richting veranderen bij een dreigende botsing en een object ontwijken. De grenswaarden zijn met de opdrachtgever besproken en staan hieronder bij de afspraken.

Realistisch

Haalbaar met het geleverde chassis en een afstandssensor binnen het budget van 50 euro. De marges zijn ruim gekozen, omdat de sensor niet exact meet. De rijsnelheid houden we laag; anders zijn de remafstand en de afwijking niet te halen.

Tijdgebonden

Uitwerken in periode 1. Besturing en uitwijken testen rond de projectweek (week 45). Aantonen bij de demo van het tussenproduct in week 51 en opnieuw bij de eindoplevering in periode 2.

Afspraken

F2 – Er zijn 3 testritten van 2 minuten; minimaal 2 daarvan moeten slagen. Het testparcours is een afgebakende ruimte van ongeveer 2 bij 3 meter met kartonnen dozen als obstakels.

F2.1 – De gemiddelde snelheid is minimaal 0,20 m/s. Een afwijking van 40 cm over 2 m is acceptabel.

F2.2 – Alleen obstakels recht vooruit hoeven gezien te worden. Een meetafwijking van 5 cm is acceptabel.

F2.3 – Eén fout op 10 pogingen is acceptabel, met minimaal 2 cm ruimte tot het obstakel.

F2.4 – Achteruitrijden zonder te meten mag, over maximaal 30 cm.

F2.5 – Starten en stoppen kan via het menu en via de USART. Na een stopcommando staat de auto binnen 1 s stil in plaats van 5 s, zodat het als noodstop werkt.

## F3 – Slave mode

In slave mode volgt de robot-car zelfstandig een lijn en rijdt hij achter een voorganger aan. Stopt de voorganger, dan stopt de robot-car ook, en hij vertrekt pas weer als de voorganger vertrekt. Zo kunnen meerdere auto's als een treintje achter elkaar rijden.

Specifiek

Wie: de robot-car in slave mode. Wat: een lijn volgen, afstand houden tot de voorganger en meestoppen. Waar: op het lijnparcours in de projectruimte. Wanneer: zodra slave mode is ingeschakeld.

Meetbaar

De robot-car rijdt binnen 5 seconden na het inschakelen zelfstandig in slave mode. Hij blijft binnen 5 cm van de lijn en houdt een afstand tussen 10 en 50 cm tot zijn voorganger. Nadat de voorganger is gestopt, staat hij binnen 2 seconden stil en hij vertrekt pas weer als de voorganger vertrekt. Raakt hij de lijn kwijt, dan stopt hij.

Acceptabel

Dit komt overeen met de concepteisen: een lijn volgen, een voorganger volgen tijdens het lijn volgen en stoppen zodra de voorganger stopt. De afstanden en tijden zijn met de opdrachtgever besproken.

Realistisch

Voor het lijn volgen gebruiken we lijnsensoren onder de auto en voor de afstand tot de voorganger dezelfde afstandssensor als in de autonome mode. Beide passen binnen het budget en de besturing lijkt sterk op die van F2.

Tijdgebonden

Uitwerken in periode 1. Het lijn volgen en het volgen van de voorganger testen we rond de projectweek (week 45). Aangetoond bij het tussenproduct in week 51 en bij de eindoplevering in periode 2.

Afspraken

F3 – De lijn is zwart tape van 1 tot 2 cm breed op een lichte vloer, met bochten maar zonder kruisingen.

F3.1 – Een afwijking van 5 cm is acceptabel. Raakt de auto de lijn kwijt, dan stopt hij.

F3.2 – De voorganger is een andere robot-car met een reflector aan de achterkant (T7).

F3.3 – 2 seconden tot stilstand is voldoende.

## F4 – Remote control

De robot-car kan met een remote control worden bestuurd. De gebruiker rijdt hem vooruit en achteruit, draait links- en rechtsom en stelt de snelheid in. Deze mode is bedoeld om de auto handmatig te bedienen wanneer hij niet zelfstandig rijdt.

Specifiek

Wie: de gebruiker met de remote control. Wat: de rijrichting en de snelheid van de robot-car bepalen. Waar: op het testparcours in de projectruimte. Wanneer: zodra de mode Remote control is gekozen.

Meetbaar

De robot-car rijdt op commando vooruit en achteruit en draait links- en rechtsom. Hij reageert binnen 250 ms op de bediening. De snelheid is via de remote control in drie standen instelbaar. Elk commando testen we minimaal 3 keer en het moet iedere keer werken.

Acceptabel

De bediening is voor de gebruiker logisch: een bediening voor de richting en een voor de snelheid. De auto voert alleen uit wat de gebruiker aangeeft en rijdt niet uit zichzelf verder.

Realistisch

De aansturing van de motoren is al beschreven in F1; de remote control stuurt daar alleen commando's naartoe. De verbinding tussen de remote control en de auto is onderdeel van het project.

Tijdgebonden

De remote control werkt rond de projectweek (week 45). We tonen hem bij de demo van het tussenproduct in week 51 en bij de eindoplevering in periode 2.

Afspraken

F4 – Maximaal 250 ms vertraging tussen een commando en de reactie van de auto.

F4.2 – De auto draait om zijn eigen as, net als bij F1.2.

F4.3 – Dezelfde drie snelheidsstanden als bij F1.3, te kiezen met een knop op de remote control.

## F5 – Display

Op het display staat de informatie die de gebruiker nodig heeft om de robot-car te bedienen: de rijrichting, de snelheidsstand, de actieve mode, de gebruikstijd en het batterijniveau. De gebruiker moet in een oogopslag kunnen zien wat de auto doet.

Specifiek

Wie: de gebruiker van de robot-car. Wat: de rijrichting, de snelheidsstand, de actieve mode, de totale gebruikstijd, de tijd in de huidige mode en het batterijniveau aflezen. Waar: op het display op de auto. Wanneer: zolang de robot-car is ingeschakeld.

Meetbaar

Het display toont de rijrichting (vooruit, achteruit, links of rechts) met de snelheidsstand, en verandert mee zodra de auto van richting wisselt. De actieve mode staat leesbaar in beeld. De totale gebruikstijd en de tijd in de huidige mode staan in seconden op het scherm en lopen zichtbaar op. Het batterijniveau staat in procenten in beeld en knippert onder 20 %.

Acceptabel

De gegevens zijn zonder uitleg te begrijpen en blijven leesbaar terwijl de auto rijdt. De rijrichting en de mode zijn duidelijk van elkaar te onderscheiden.

Realistisch

De rijrichting, de snelheidsstand en de mode zijn al in de software bekend, dus die hoeven alleen te worden weergegeven. De tijd houdt de microcontroller zelf bij. Het batterijniveau vraagt een extra meting en staat daarom op Could.

Tijdgebonden

Het display met de rijrichting, de mode en de gebruikstijd werkt bij de demo van het tussenproduct in week 51. Het batterijniveau volgt in periode 2, als de tijd het toelaat.

Afspraken

F5 – Het display zit op de auto zelf.

F5.2 – Zowel de mode als de snelheidsstand staan op het display.

F5.3 – De tijden staan in seconden.

F5.4 – Het batterijniveau staat in procenten; onder 20 % knippert het als waarschuwing.

## F6 – Mode selecteren via het menu

Via een menu op de auto kiest de gebruiker in welke mode de robot-car rijdt: Autonoom, Slave of Remote control. De gekozen mode wordt op het display getoond en daarna geactiveerd.

Specifiek

Wie: de gebruiker. Wat: een van de drie modes selecteren. Waar: in het menu op het display van de auto, bediend met drie toetsen. Wanneer: voordat de gebruiker gaat rijden, of wanneer de gebruiker van mode wil wisselen.

Meetbaar

Alle drie de modes zijn via het menu te kiezen en de gekozen mode wordt correct op het display weergegeven. De gebruiker kan binnen 10 seconden een mode selecteren. Bij het wisselen van mode stopt de auto eerst. We testen dit per mode minimaal 3 keer en het moet iedere keer werken.

Acceptabel

Het menu is te bedienen zonder handleiding en de drie modes zijn goed van elkaar te onderscheiden.

Realistisch

De functionaliteit van de drie modes bouwen we al in F2, F3 en F4. Het menu hoeft die alleen te selecteren en te starten.

Tijdgebonden

Het menu werkt bij de demo van het tussenproduct in week 51, zodat we de drie modes daar achter elkaar kunnen laten zien.

Afspraken

F6 – Het menu zit op de auto en wordt bediend met drie knoppen: omhoog, omlaag en OK.

F6.1 t/m F6.3 – Van mode wisselen mag tijdens het rijden; de auto stopt dan eerst.

## F7 – Gebruikstijd bewaren

De robot-car houdt bij hoe lang hij in gebruik is. Die tijd blijft bewaard wanneer de auto wordt uitgeschakeld, zodat de teller na het opnieuw opstarten verder loopt vanaf de opgeslagen waarde.

Specifiek

Wie: de robot-car. Wat: de totale gebruikstijd bijhouden, opslaan en na het opstarten weer inlezen. Waar: in het geheugen van de auto. Wanneer: tijdens het gebruik, elke minuut.

Meetbaar

De totale gebruikstijd staat in seconden op het display en loopt op zolang de auto aanstaat. De tijd wordt elke minuut opgeslagen, dus bij het uitschakelen gaat hooguit een minuut verloren. Na het opnieuw inschakelen telt de auto vanaf de opgeslagen waarde verder. Dit moet bij minimaal 3 keer uit- en weer inschakelen goed gaan.

Acceptabel

De gebruiker kan de totale gebruikstijd eenvoudig aflezen en de tijd gaat niet verloren bij het uitschakelen. De opdrachtgever accepteert de werking wanneer de teller na het opstarten correct verdergaat.

Realistisch

De microcontroller heeft geheugen dat zijn inhoud behoudt zonder voeding, dus de waarde kan bij het opstarten opnieuw worden ingelezen. Het gaat om een enkel getal, dus er is weinig opslag nodig.

Tijdgebonden

We werken dit uit in periode 2, nadat de gebruikstijd op het display werkt (F5.3), en tonen het bij de eindoplevering.

Afspraken

F7 – De tijd wordt elke minuut opgeslagen, niet alleen bij het uitschakelen. Zo gaat er ook weinig verloren als de batterij leeg raakt.

F7 – De teller kan via het menu worden gereset.

# Technische Specificaties

Naast de functionele eisen stelt de opdrachtgever eisen aan het product zelf, zoals de microcontroller, de programmeertaal, de aansturing van de motoren en de voeding. T1 tot en met T7 komen uit de concepteisen van de projecthandleiding. T8 tot en met T11 hebben we toegevoegd, omdat de functionele eisen daar niet zonder kunnen.

Tabel 2 – Technische specificaties

# | MoSCoW | Omschrijving | Herleidbaar naar

T1 | M | De besturing van de robot-car wordt gerealiseerd met een ATmega328(p)-microcontroller. | F1, F2, F3
T1.1 | M | In periode 1 wordt het tussenproduct via rapid prototyping gerealiseerd met de Arduino IDE op dezelfde ATmega328(p); in periode 2 wordt de microcontroller aangestuurd door rechtstreeks de registers te bewerken. | F1, F2, F3
T2 | M | De software voor de microcontroller wordt geschreven in de programmeertaal C. | F1, F2, F3
T3 | M | De C-code voldoet aan de programmeerrichtlijnen zoals aangeleerd in de opleiding (C-style programming guidelines v3.1). | F1, F2, F3
T4 | M | De dc-motoren van de robot-car worden aangedreven via een H-brug, zodat beide draairichtingen per motor mogelijk zijn. | F1.1, F1.2
T4.1 | M | Voor het regelen van de motorsnelheid wordt gebruikgemaakt van de PWM van de microcontroller; er wordt geen aanvullende hardware voor snelheidsregeling toegepast. | F1.3
T4.2 | M | Voor de H-brug wordt gebruikgemaakt van een L298N dual H-bridge driverboard. | F1.1, F1.2
T4.3 | M | De robot-car wordt aangedreven door de dc-motoren van het door de opdrachtgever geleverde chassis. | F1
T5 | M | Voor testdoeleinden kan de robot-car bestuurd worden via de seriële interface, de USART van de ATmega328(p). | F1, F2.5
T5.1 | M | Via de USART kan de robot-car vooruit en achteruit rijden. | F1.1
T5.2 | M | Via de USART kan de robot-car links- en rechtsom draaien. | F1.2
T5.3 | M | Via de USART kan de snelheidsstand van de robot-car worden ingesteld. | F1.3
T5.4 | M | Via de USART kan de autonome mode worden gestart en gestopt. | F2.5
T6 | M | Voor de voeding van de robot-car wordt gebruikgemaakt van batterijen. | F1, F2, F3
T6.1 | M | De schakeling is beveiligd tegen het verkeerd om aansluiten van de voeding. | –
T6.2 | M | De batterijen zijn beveiligd tegen kortsluiting door een beveiliging die zo dicht mogelijk bij de batterij is geplaatst. | –
T6.3 | M | Een LED geeft aan dat de robot-car wordt gevoed; deze LED brandt continu zolang de robot-car is ingeschakeld. | F1, F2, F3
T6.4 | M | De voedingsspanning van de microcontroller blijft binnen het door de fabrikant toegestane bereik, ook wanneer alle motoren gelijktijdig maximaal worden belast. | F1, F2, F3
T6.5 | C | De batterijspanning is voor de microcontroller meetbaar, zodat het batterijniveau kan worden weergegeven. | F5.4
T7 | M | De achterzijde van de robot-car is voorzien van een reflector, zodat deze robot-car op zijn beurt door een andere robot-car gevolgd kan worden. | F3.2
T8 | M | De robot-car meet de vrije ruimte recht vooruit met een afstandssensor. | F2.1 t/m F2.4, F3.2
T8.1 | M | De afstandssensor heeft een meetbereik van ten minste 10 tot 50 cm. | F2.2, F3.2
T8.2 | M | De afstandssensor levert ten minste 5 metingen per seconde. | F2.2
T9 | M | De robot-car detecteert de te volgen lijn met een lijnsensor aan de onderzijde van het chassis. | F3.1
T9.1 | M | De lijnsensor detecteert zwart tape van 1 tot 2 cm breed op het linoleum van de gang op de begane grond van gebouw R29. | F3.1
T9.2 | M | De lijnsensor kan onderscheiden of de lijn zich links van, onder, of rechts van het midden van de robot-car bevindt, zodat de afwijking kan worden bijgestuurd. | F3.1
T10 | M | De robot-car is voorzien van bediening op de auto zelf, bestaande uit een display en bedieningstoetsen. | F5, F6
T10.1 | M | Het display geeft vier regels gelijktijdig weer. | F5.1 t/m F5.4
T10.2 | S | De bediening bestaat uit drie toetsen: omhoog, omlaag en OK. | F6
T11 | C | Aan de achterzijde van de robot-car zitten twee LED's, links en rechts, die de draairichting aangeven. | F1.4

## Budgeteisen

Tabel 3 – Budgeteisen

# | MoSCoW | Omschrijving | Herleidbaar naar

B1 | M | Het chassis met de dc-motoren wordt geleverd door de opdrachtgever. | T4.3
B2 | M | De aanvullende kosten voor het prototype bedragen maximaal € 50,- aan onderdelen. Willen wij meer besteden, dan wordt dit vooraf met de tutor overlegd. | T8, T9, T10
B3 | M | Kosten voor het gebruik van het Fablab worden meegenomen in de berekening van de uiteindelijke productiekosten, ook wanneer ze voor het project zelf niet in rekening worden gebracht. | –

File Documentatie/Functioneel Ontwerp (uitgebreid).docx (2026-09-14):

Functioneel Ontwerp

Specificatie van de systeemfuncties, use-cases en gebruikersvereisten

Auteurs: | Tygo Poodt (2187406), Nathan Heuker of Hoek (2176586), Mohammed Özdemir (2172114), Floris Sevink (2186617), Milan Veulings (2190942), Mathijs Tijans (2192954)
Schoolbegeleider: | Michel Lennard De Boer – HAN University of Applied Sciences
Opdrachtgever: | Peter Bijl – HAN University of Applied Sciences
Bedrijfsnaam: | Q-Dat Systems – Groep 5
Versie: | V1.2
Datum: | 11-09-2026

Versiebeheer

Versienummer | Datum | Aanpassing
1.0 | 4-9-2026 | Tygo Poodt (2187406) – Template documentatie aangemaakt
1.1 | 11-9-2026 | Tygo Poodt (2187406), Nathan Heuker of Hoek (2176586), Mohammed Özdemir (2172114), Floris Sevink (2186617), Milan Veulings (2190942), Mathijs Tijans (2192954) - Afspraken met de opdrachtgever verwerkt
1.2 | 11-9-2026 | Tygo Poodt (2187406) – Definitieve versie(alles samengevoegd) en Won't haves toegevoegd

# Inleiding

Voor je ligt het functioneel ontwerp voor ons robotauto-project op de HAN University of Applied Sciences. Wij voeren deze opdracht uit voor onze docent en opdrachtgever Peter Bijl, met Michel Lennard De Boer als onze schoolbegeleider.

Kort gezegd gaan we een slimme robotauto bouwen die op drie manieren kan werken. De auto moet helemaal zelfstandig door een parcours kunnen rijden zonder ergens tegenaan te botsen. Ook moet hij in een treintje achter een andere auto aan kunnen rijden over een lijn. Tot slot moet je hem gewoon zelf kunnen besturen met een remote control. Op een schermpje willen we handige info laten zien, zoals de snelheid en in welke stand de auto staat.

Het doel van dit document is simpel: we willen laten zien hoe we dit voor ons zien en wat de auto straks allemaal moet kunnen. We kijken hier puur naar de werking en nog niet naar de precieze techniek of code daarachter. Zo weten Peter Bijl en wij vanaf het begin zeker dat we op één lijn zitten over wat we gaan opleveren.

De eerste versie van dit document bevatte nog open vragen aan de opdrachtgever. Die hebben we met Peter Bijl besproken. Hij liet de meeste keuzes aan ons over. De antwoorden en onze keuzes zijn in deze versie verwerkt.

Eerst zetten we alle eisen op een rij met de MoSCoW-methode, zodat meteen duidelijk is wat er sowieso in moet zitten en wat eventueel later pas komt. Daarna maken we elke functie én elke deeleis meetbaar (SMART), met per functie de gemaakte afspraken.

# Functionele Eisen

In dit hoofdstuk staan alle functionele eisen van het project. Deze eisen beschrijven precies wat de robot-car en het besturingssysteem moeten kunnen en hoe het systeem zich gedraagt in verschillende situaties. De technische uitwerking (zoals de exacte code of printplaat) laten we hier buiten beschouwing; we focussen ons puur op de functies. Onderaan de tabel staat met een W wat we bewust niet doen (Won't have).

Tabel 1 – Functionele eisen

# | MoSCoW | Omschrijving

F1 | M | De robot-car moet kunnen rijden; zonder deze basisfunctie is er geen robot-car.
F1.1 | M | De robot-car rijdt vooruit en achteruit door beide motoren in dezelfde richting te laten draaien.
F1.2 | M | De robot-car draait links- en rechtsom doordat één wiel stilstaat en het andere wiel draait, zodat hij bij vastlopen een andere route kan kiezen.
F1.3 | S | De snelheid van de robot-car is instelbaar met een variabel vermogen tussen 0% en 100%, ook tijdens het rijden.
F1.4 | C | LED-richtingaanwijzers voor en achter geven aan welke kant de robot-car op draait.
F2 | M | In de mode Autonoom rijdt de robot-car zelfstandig door het testparcours, minimaal 2 minuten achter elkaar zonder ingrijpen en zonder een obstakel te raken.
F2.1 | S | Staat er geen obstakel voor de robot-car, dan rijdt hij rechtdoor.
F2.2 | M | De robot-car ziet obstakels recht vooruit op een afstand tussen 10 en 50 cm.
F2.3 | M | Staat er een obstakel dichterbij dan 20 cm, dan stopt de robot-car zonder het obstakel te raken.
F2.4 | M | Na het stoppen kiest de robot-car zelf een nieuwe richting en rijdt hij verder.
F2.5 | M | De autonome mode kan via het menu en via de USART worden gestart en gestopt.
F2.6 | C | Het autonoom rijden testen we ook in een simulatie in MATLAB met ons eigen 3D-model van de auto.
F3 | M | De robot-car rijdt binnen 5 seconden na het inschakelen van slave mode zelfstandig in slave mode.
F3.1 | M | De robot-car volgt een lijn met een maximale afwijking van 5 cm ten opzichte van die lijn. Raakt hij de lijn kwijt, dan stopt hij.
F3.2 | M | Tijdens het volgen van de lijn volgt de robot-car ook een voorganger op een afstand tussen 10 en 50 cm, waarbij hij de lijn blijft volgen en achter de voorganger blijft rijden. De voorganger is een andere robot-car. Bij het testen mag dat ook een voet zijn.
F3.3 | M | De robot-car staat binnen 2 seconden stil nadat de voorganger is gestopt en vertrekt pas weer wanneer de voorganger vertrekt.
F4 | M | De robot-car kan via een remote control worden bestuurd en reageert binnen 250 ms op een commando.
F4.1 | M | Via de remote control rijdt de robot-car vooruit en achteruit.
F4.2 | M | Via de joystick op de remote control draait de robot-car links- en rechtsom.
F4.3 | S | Via de remote control is de snelheid van de robot-car instelbaar, ook tijdens het rijden.
F5 | M | De belangrijkste gegevens worden weergegeven op een display op de robot-car.
F5.1 | M | Het display geeft de rijrichting weer: vooruit, achteruit, links of rechts.
F5.2 | M | Het display geeft weer in welke mode de robot-car zich bevindt.
F5.3 | M | Het display geeft de totale gebruikstijd weer in seconden.
F5.4 | M | Het display geeft de snelheid weer in procenten van de maximale snelheid.
F6 | S | Via een menu op de robot-car en via de remote control kan de mode worden geselecteerd. Bij het wisselen van mode stopt de auto eerst.
F6.1 | S | Via het menu kan de mode Autonoom worden geselecteerd, waarin de robot-car zelfstandig rijdt en obstakels ontwijkt volgens F2.
F6.2 | S | Via het menu kan de mode Slave worden geselecteerd, waarin de robot-car een lijn en een voorganger volgt volgens F3.
F6.3 | S | Via het menu kan de mode Remote control worden geselecteerd, waarin de robot-car met de remote control wordt bestuurd volgens F4.
F7 | C | De robot-car slaat de totale gebruikstijd elke minuut op en telt na het opnieuw opstarten verder vanaf de opgeslagen waarde. Via het menu kan de teller worden gereset.
W1 | W | De robot-car hoeft geen obstakels achter of naast zich te zien.
W2 | W | De werkelijke snelheid wordt niet gemeten; de snelheid staat alleen in procenten van de maximale snelheid.
W3 | W | Het menu krijgt geen touchscreen.
W4 | W | De remote control hoeft niet waterdicht te zijn.
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

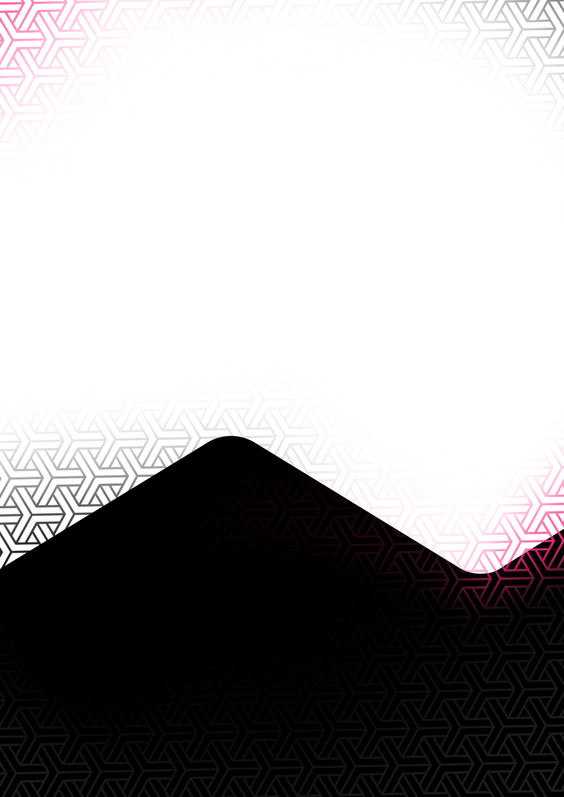
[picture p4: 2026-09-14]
Documentatie/Main Background Q-Dat.png

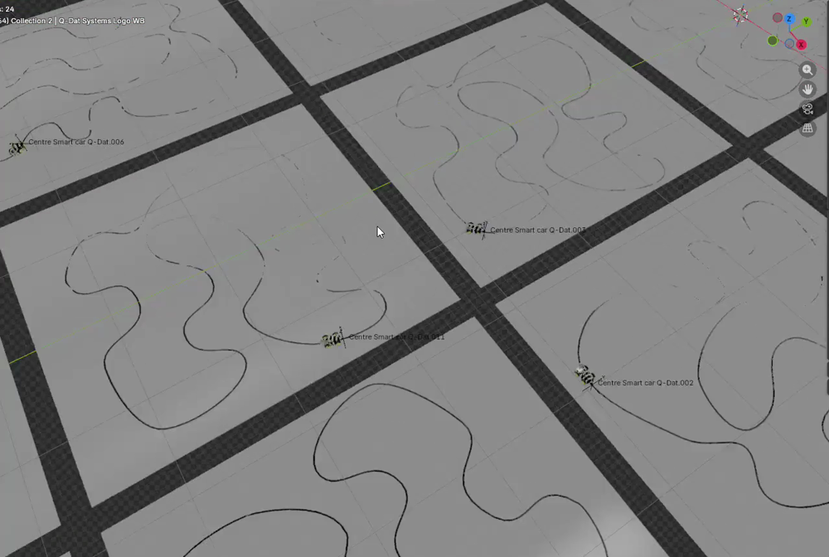
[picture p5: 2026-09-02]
Software/Simulations/preview.png

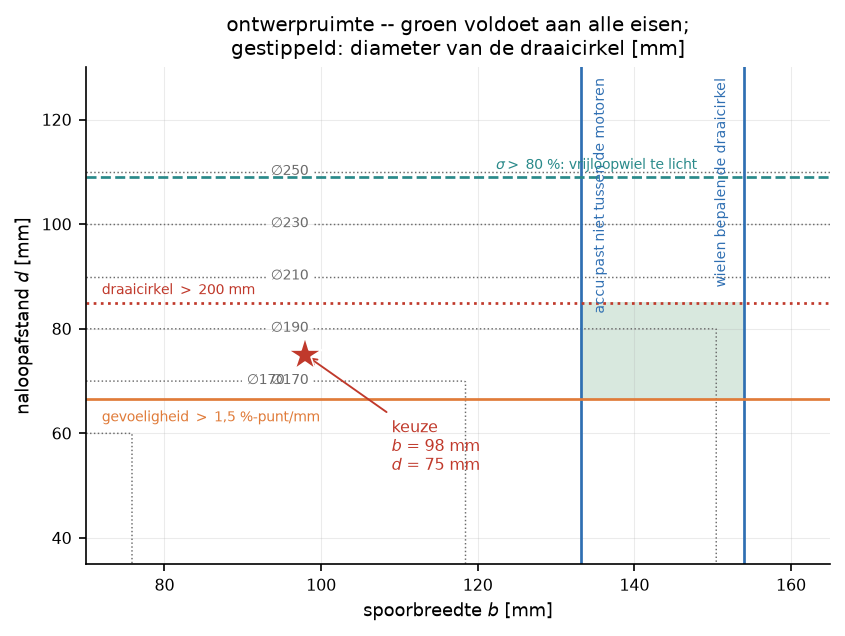
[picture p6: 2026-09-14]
Documentatie/Frame-analyse/figuren/f4_ontwerpruimte.png

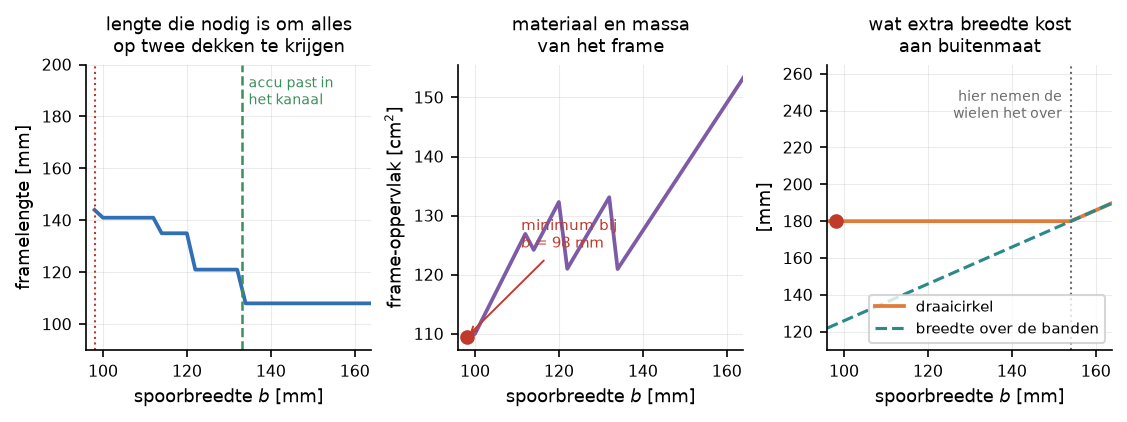
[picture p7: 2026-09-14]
Documentatie/Frame-analyse/figuren/f7_breedte.png

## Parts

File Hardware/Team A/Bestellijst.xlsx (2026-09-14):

Bestellijst Team A
Robot-car | Project 1 NL | gemaakt door Tygo | 03-09-2026
Alles wat nodig is om de Robot-car te laten rijden, een lijn te volgen en een voorganger te volgen. Budget: max € 50,- (eis B1). Bestellen via ARLE - R29 begane grond, ruimte H0.25.
Nr | Component | Waarvoor | Aantal | Prijs | Totaal | Link / bestelcode
1 | HC-SR04 ultrasonic module | Afstand meten: niet botsen (F2) en voorganger volgen (F3.2/F3.3) | 2 | €2.95 | €5.90 | benselectronics.nl - SKU EZ26 (https://benselectronics.nl/hc-sr04-ultrasonic-module/)
2 | 4 kanaals line tracker | Zwarte lijn op de vloer volgen (F3.1) | 1 | €5.95 | €5.95 | benselectronics.nl - SKU Q64 (https://benselectronics.nl/4-kanaals-line-tracker/)
3 | L298N Dual H-Bridge motordriver | Motoren aansturen met PWM (F1.1 t/m F1.3) | 1 | €4.00 | €4.00 | Schatting - vraag prijs en voorraad bij ARLE
4 | TPS76650 spanningsregelaar | Stabiele 5 V van de batterij naar de microcontroller | 1 | €5.00 | €5.00 | Farnell bestelcode 8461430 - prijs nog navragen
5 | Batterijhouder 6x AA met draad | Voeding van de auto (T6.1) | 1 | €3.00 | €3.00 | Schatting - vraag prijs bij ARLE
6 | Batterij AA | Voeding van de auto (T6.1) | 6 | €1.50 | €9.00 | Schatting - vraag prijs bij ARLE
7 | Zekeringhouder + zekering 3 A | Kortsluitbeveiliging vlakbij de batterij (T6.3) | 1 | €1.50 | €1.50 | Schatting - vraag prijs bij ARLE
8 | Diode of P-MOSFET | Beveiliging tegen verkeerd om aansluiten (T6.2) | 1 | €1.50 | €1.50 | Schatting - vraag prijs bij ARLE
9 | Schakelaar 3 A | Hoofdschakelaar in de batterijleiding | 1 | €1.50 | €1.50 | Schatting - vraag prijs bij ARLE
10 | LED 5 mm geel | Richting aangeven bij draaien (F1.4) | 2 | €0.25 | €0.50 | Schatting - vraag prijs bij ARLE
11 | LED 5 mm groen | Aangeven dat de auto gevoed wordt (T7) | 1 | €0.25 | €0.25 | Schatting - vraag prijs bij ARLE
12 | Weerstand 220 ohm, 1/4 W | Voorschakelweerstand bij de drie LEDs | 3 | €0.10 | €0.30 | Schatting - vraag prijs bij ARLE
13 | Dupontdraad set male-female | Bedrading sensoren naar de microcontroller | 1 | €3.00 | €3.00 | Schatting - vraag prijs bij ARLE
14 | Reflecterende tape | Reflector achterop, zodat deze auto ook gevolgd kan worden (slave mode) | 1 | €2.50 | €2.50 | Schatting
15 | Zwart tape 19 mm | Eigen testlijn om de lijnvolger af te regelen | 1 | €2.00 | €2.00 | Schatting
 |  |  |  | Totaal | €45.90
 |  |  |  | Budget | €50.00
Let op: alleen de HC-SR04 en de line tracker hebben een gecontroleerde prijs (benselectronics.nl, 03-09-2026). Alle andere prijzen zijn schattingen - vraag ze na bij de componentenbalie. Ligt iets daar op voorraad, dan kost het niets en gaat het totaal omlaag; is iets duurder, dan gaat het totaal omhoog. Chassis en motoren komen van de opdrachtgever (eis B1).

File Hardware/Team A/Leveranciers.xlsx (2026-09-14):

Webshops - Team A
Robot-car | Project 1 NL | gemaakt door Tygo | 03-09-2026
Let op: we bestellen niet zelf. Zoek hier het onderdeel en de prijs op, en geef die door aan ARLE (R29 begane grond, H0.25). ARLE plaatst de bestelling bij hun eigen preferred suppliers.
Webshop | Link | Waarvoor | Mogen we hier bestellen?
Bens Electronics | https://benselectronics.nl/ | Sensoren en modules: HC-SR04, line tracker, kleine onderdelen | Ja - staat in de projecthandleiding
Farnell | https://nl.farnell.com/ | IC-s en losse componenten op bestelcode, o.a. de TPS76650 (8461430) | Ja - staat in de projecthandleiding
TinyTronics | https://www.tinytronics.nl/ | Arduino-modules, sensoren, motordrivers, batterijhouders | Navragen bij ARLE
Kiwi Electronics | https://www.kiwi-electronics.com/ | Arduino-modules en sensoren | Navragen bij ARLE
Antratek | https://www.antratek.nl/ | Embedded modules en sensoren | Navragen bij ARLE
Otronic | https://www.otronic.nl/ | Goedkope modules en losse onderdelen | Navragen bij ARLE
Conrad | https://www.conrad.nl/ | Breed assortiment, ook gereedschap en behuizingen | Navragen bij ARLE
RS Components | https://nl.rs-online.com/ | Professionele componenten met datasheets | Navragen bij ARLE
Mouser | https://www.mouser.nl/ | Professionele componenten met datasheets | Navragen bij ARLE
Alleen Bens Electronics en Farnell worden in de projecthandleiding genoemd (hoofdstuk 3.7). De handleiding zegt wel dat ARLE een aantal preferred suppliers heeft, maar noemt ze niet - vraag die lijst op aan de balie en vul hem hier aan. Meer dan 50 euro uitgeven mag alleen na overleg met de tutor (3.10).

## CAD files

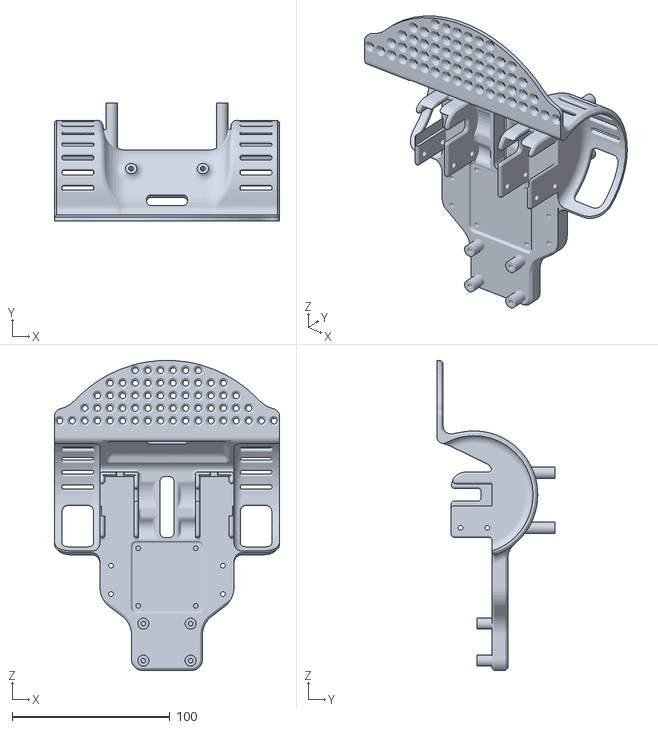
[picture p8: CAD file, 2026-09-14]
Hardware/3D Files/3d print main body.STL
143.0 x 75.0 x 196.7

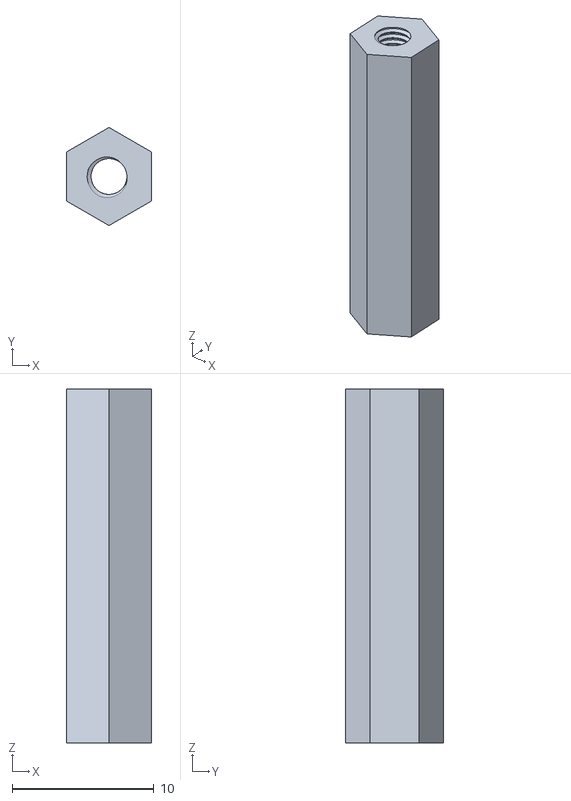
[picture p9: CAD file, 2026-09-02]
Hardware/3D Files/stl assembly/4WD assemblySTL - 4WD arduino buggy.stp-1 brass standoff.stp-4.STL
6.00 x 6.93 x 25.0

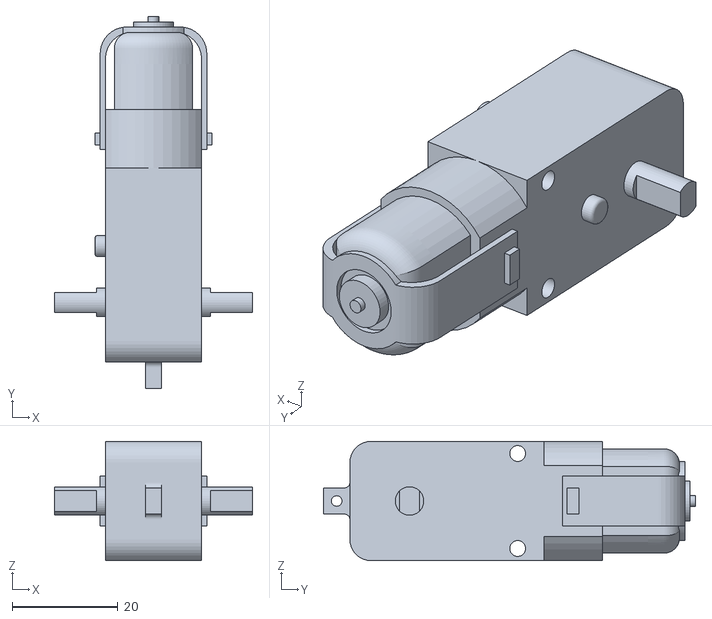
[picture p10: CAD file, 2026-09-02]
Hardware/3D Files/stl assembly/4WD assemblySTL - 4WD arduino buggy.stp-1 Motor_Gear_Box v4.stp-1.STL
37.6 x 70.5 x 22.6

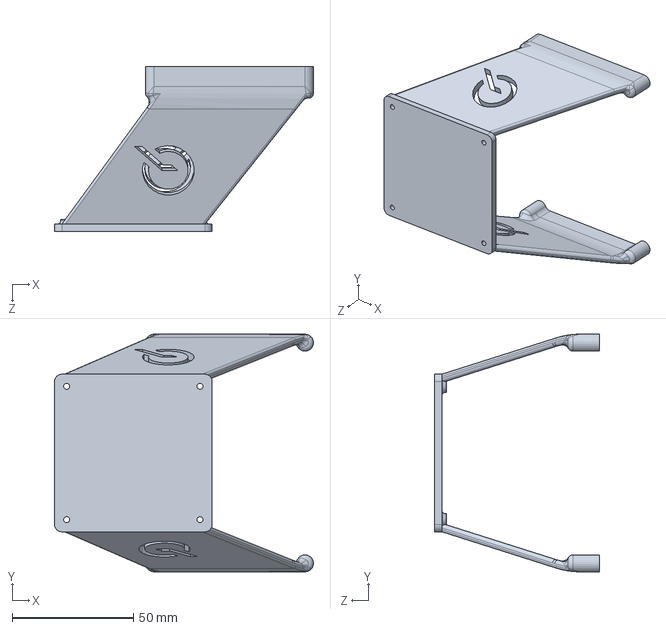
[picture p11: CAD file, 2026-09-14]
Hardware/3D Files/Solidworks/Atmega328P Main body.SLDPRT
106.8 x 98.0 x 68.0 mm

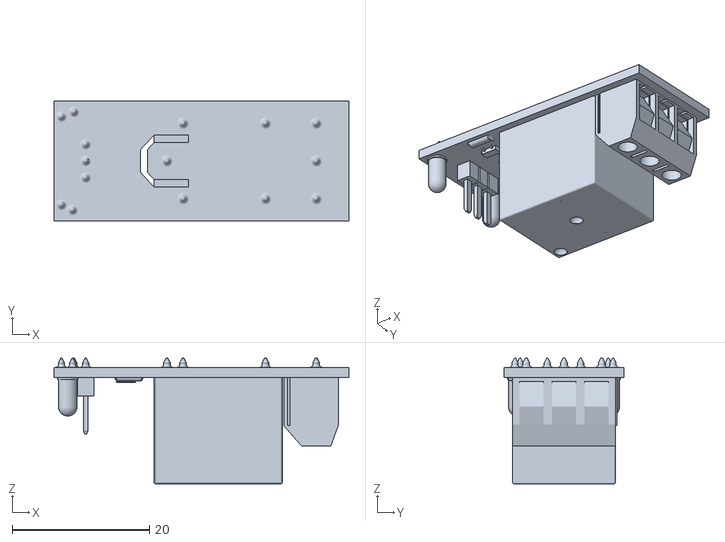
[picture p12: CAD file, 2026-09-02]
Hardware/3D Files/stl assembly/4WD assemblySTL - Arduino relay.step-1.STL
43.0 x 17.5 x 18.4

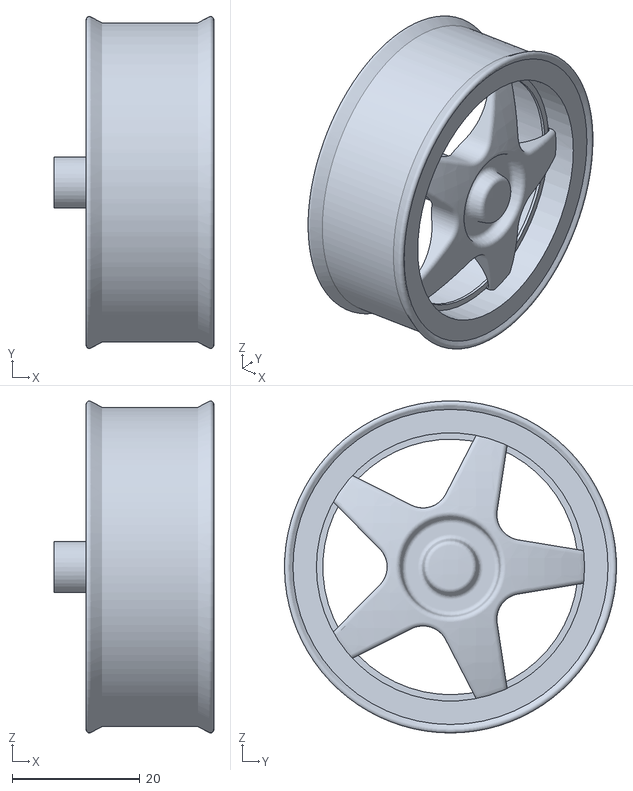
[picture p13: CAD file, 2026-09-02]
Hardware/3D Files/stl assembly/4WD assemblySTL - 4WD arduino buggy.stp-1 4WD buggy wheel v5_1_2.stp-1 4WD buggy wheel v5_1_1.stp-1.STL
25.0 x 52.0 x 52.0

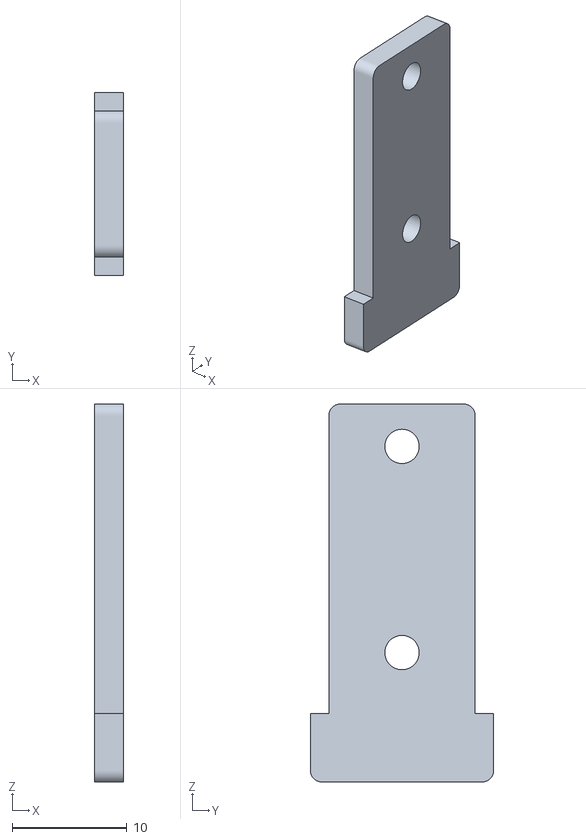
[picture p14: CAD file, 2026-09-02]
Hardware/3D Files/stl assembly/4WD assemblySTL - 4WD arduino buggy.stp-1 motor mount.stp-8.STL
2.50 x 16.0 x 33.0

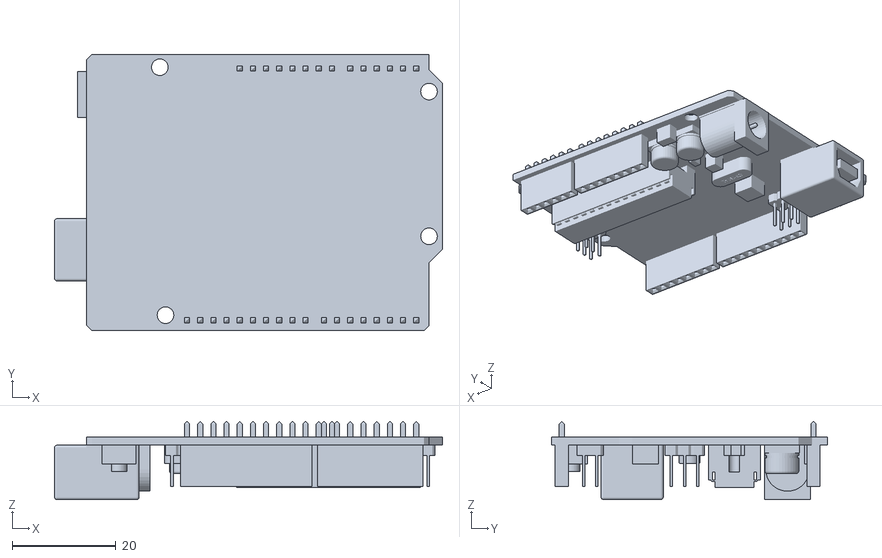
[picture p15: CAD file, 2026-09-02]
Hardware/3D Files/stl assembly/4WD assemblySTL - ArduinoUNOR3.step-1.STL
74.8 x 53.3 x 15.1

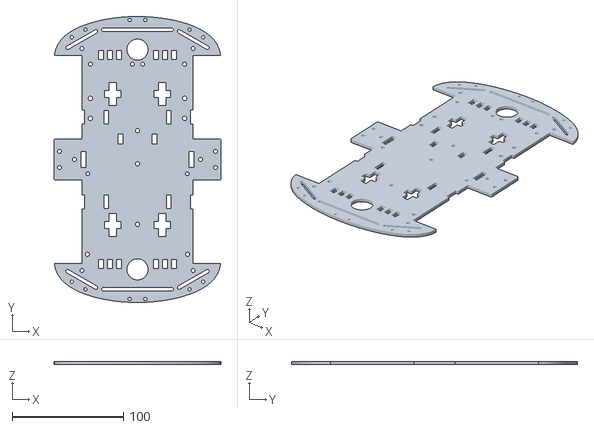
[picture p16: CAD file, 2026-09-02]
Hardware/3D Files/stl assembly/4WD assemblySTL - 4WD arduino buggy.stp-1 buggy chassis orig v3.stp-2.STL
150.0 x 257.0 x 3.00

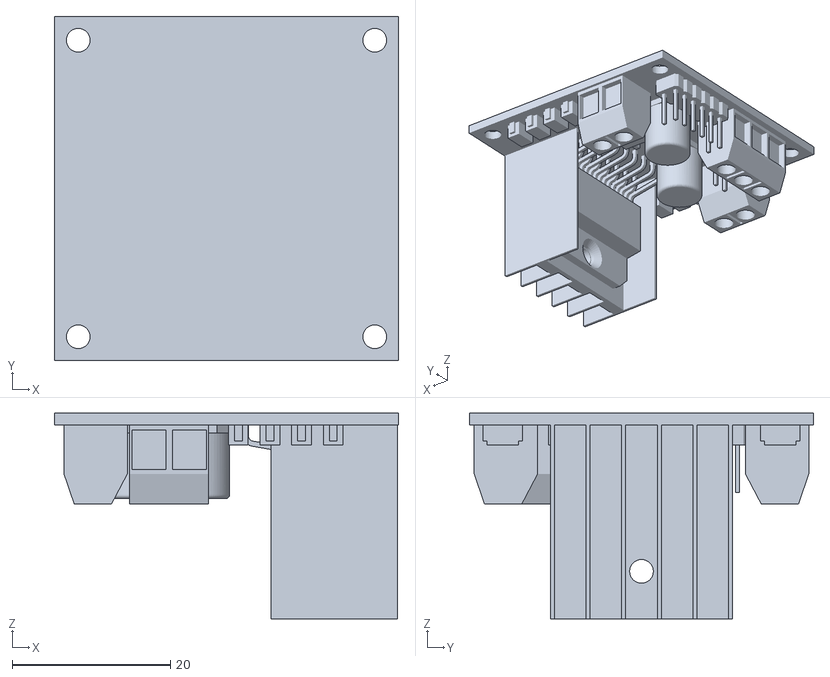
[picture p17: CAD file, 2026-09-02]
Hardware/3D Files/stl assembly/4WD assemblySTL - L298N Motor Driver.step-1.STL
43.5 x 43.5 x 26.0

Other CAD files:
Hardware/3D Files/Robot_Smart_Car_Kit_v2.SLDASM
Hardware/3D Files/Main frame.SLDPRT
Hardware/3D Files/Parts/mirrormotormetwiel.SLDASM.SLDASM
Hardware/3D Files/3d print main body - plat.stl
Hardware/3D Files/stl assembly/4WD assemblySTL - 4WD arduino buggy.stp-1 brass standoff.stp-5.STL
Hardware/3D Files/stl assembly/4WD assemblySTL - 4WD arduino buggy.stp-1 4WD buggy wheel v5_2_1.stp-1 4WD buggy wheel v5_2.stp-1.STL
Hardware/3D Files/stl assembly/4WD assemblySTL - 4WD arduino buggy.stp-1 4WD buggy wheel v5_3_1.stp-1 4WD buggy wheel v5_3.stp-1.STL
Hardware/3D Files/stl assembly/4WD assemblySTL - 4WD arduino buggy.stp-1 buggy chassis orig v3.stp-1.STL
Hardware/3D Files/Body opgedeeld/Body deel 1 - montageplaat.stl
Hardware/3D Files/Body opgedeeld/Body deel 2 - voorplaat met wand.stl
Hardware/3D Files/Body opgedeeld/Body deel 3 - kap links.stl
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

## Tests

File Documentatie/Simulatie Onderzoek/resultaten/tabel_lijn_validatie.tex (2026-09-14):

\begin{tabular}{@{}lrrrrr@{}}
\toprule
 & voltooid & $T$ testparcours & $\bar v$ & $e_{\max}$ & gejitter \\
 & & [s] & [m/s] & [mm] & [PWM/stap] \\
\midrule
huidige sim (teken gecorrigeerd) & 30/30 & 124{,}9 & 0{,}25 & 62 & 0{,}459 \\
huidige sensoren, regelaar geoptimaliseerd & 30/30 & 72{,}8 & 0{,}42 & 43 & 0{,}021 \\
optimale sensoren, analytische $K^*$ & 30/30 & 111{,}6 & 0{,}27 & 12 & 0{,}033 \\
optimum (sensoren + regelaar) & 30/30 & 73{,}0 & 0{,}42 & 42 & 0{,}018 \\
\bottomrule
\end{tabular}

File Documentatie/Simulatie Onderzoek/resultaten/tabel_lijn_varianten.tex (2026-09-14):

\begin{tabular}{@{}lrrr@{}}
\toprule
variant (bij $L = 45$~mm) & kost $J^*$ & $T v_0/L$ & $e_{\max}$ [mm] \\
\midrule
2 sensoren & 1{,}44 & 1{,}25 & 10 \\
3 sensoren & 1{,}36 & 1{,}21 & 12 \\
4 sensoren (optimum) & 1{,}31 & 1{,}19 & 10 \\
5 sensoren & 1{,}29 & 1{,}19 & 11 \\
4 sensoren, analoog & 1{,}24 & 1{,}18 & 11 \\
4, analoog, steek 22 mm & 1{,}40 & 1{,}25 & 17 \\
\bottomrule
\end{tabular}

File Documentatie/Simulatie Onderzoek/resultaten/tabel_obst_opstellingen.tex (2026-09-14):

\begin{tabular}{@{}llrrrrr@{}}
\toprule
opstelling & koers & botsingsvrij & botsingsvrij & test & afstand & fout F2.3/2.4 \\
 & & rommel & rustig & gehaald & [m/2 min] & per stop \\
\midrule
huidig (1 recht, ongekal.) & tijd & 0\,\% & 0\,\% & 0\,\% & 1{,}5 & 3\,\% \\
\midrule
recht & tijd & 0\,\% & 0\,\% & 0\,\% & 3{,}3 & 3\,\% \\
kruis2 & tijd & 68\,\% & 59\,\% & 76\,\% & 9{,}0 & 6\,\% \\
uit2 & tijd & 27\,\% & 39\,\% & 18\,\% & 4{,}4 & 23\,\% \\
drie & tijd & 37\,\% & 37\,\% & 31\,\% & 9{,}2 & 3\,\% \\
recht & encoders & 0\,\% & 4\,\% & 0\,\% & 5{,}2 & 2\,\% \\
kruis2 & encoders & 51\,\% & 47\,\% & 51\,\% & 8{,}7 & 9\,\% \\
uit2 & encoders & 27\,\% & 28\,\% & 18\,\% & 4{,}1 & 45\,\% \\
drie & encoders & 33\,\% & 27\,\% & 25\,\% & 4{,}7 & 25\,\% \\
\bottomrule
\end{tabular}

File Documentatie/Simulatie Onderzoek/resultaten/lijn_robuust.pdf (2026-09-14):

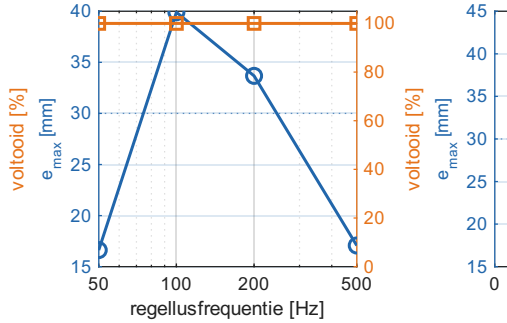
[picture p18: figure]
voltooid [%]; ellu; tie; max [mm]
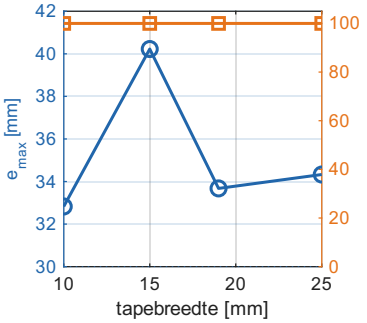
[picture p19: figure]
max [mm]
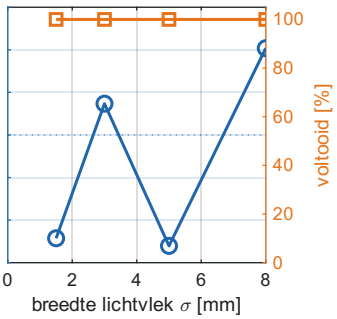
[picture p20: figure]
e lic; vle; voltooid [%]

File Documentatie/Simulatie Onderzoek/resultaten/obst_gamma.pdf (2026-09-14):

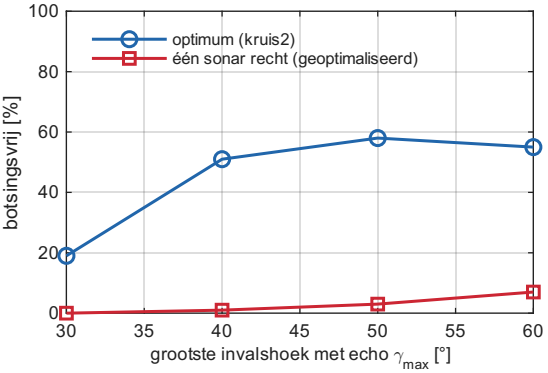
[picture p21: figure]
grootste invalshoek met echo .max; botsingsvrij [%]; optimum (kruis2) één sonar recht (geoptimaliseerd)

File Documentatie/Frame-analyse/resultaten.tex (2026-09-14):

% automatisch gegenereerd door analyse.py -- niet met de hand aanpassen
\newcommand{\RbMinPack}{73{,}2}
\newcommand{\RgapOpt}{24{,}8}
\newcommand{\RframeWOpt}{76{,}0}
\newcommand{\RbfWheel}{70{,}0}
\newcommand{\RclearTyre}{1{,}05}
\newcommand{\RtotalWOpt}{123{,}9}
\newcommand{\RWuOpt}{64}
\newcommand{\Rmtot}{0{,}539}
\newcommand{\Rmtotg}{539}
\newcommand{\RWn}{5{,}29}
\newcommand{\Rxg}{21{,}8}
\newcommand{\Rhcg}{46{,}4}
\newcommand{\RsigmaOpt}{70{,}9}
\newcommand{\RsigLo}{65}
\newcommand{\RsigHi}{80}
\newcommand{\RNdrive}{3{,}75}
\newcommand{\RNcaster}{1{,}54}
\newcommand{\RsensOpt}{1{,}33}
\newcommand{\RdSens}{67}
\newcommand{\RdLoSigma}{62{,}3}
\newcommand{\RdHiSigma}{109{,}0}
\newcommand{\RaLift}{4{,}60}
\newcommand{\RaLiftG}{0{,}47}
\newcommand{\RxgMin}{18{,}6}
\newcommand{\RaAccel}{3{,}72}
\newcommand{\RaAccelG}{0{,}38}
\newcommand{\RbRoll}{74{,}3}
\newcommand{\RaRoll}{10{,}35}
\newcommand{\RaSlip}{7{,}85}
\newcommand{\RdiagOpt}{29{,}1}
\newcommand{\RaDiag}{6{,}15}
\newcommand{\RTcaster}{23{,}0}
\newcommand{\RdsAxle}{10{,}05}
\newcommand{\RdsShaft}{0{,}209}
\newcommand{\RquantOpt}{5{,}88}
\newcommand{\RquantMin}{7{,}87}
\newcommand{\RquantShaft}{0{,}122}
\newcommand{\RcalOpt}{1{,}38}
\newcommand{\RcalMin}{1{,}84}
\newcommand{\RdriftOpt}{51}
\newcommand{\RdriftMin}{68}
\newcommand{\RquantGain}{25}
\newcommand{\RFstallEen}{1{,}55}
\newcommand{\RFstallTwee}{3{,}10}
\newcommand{\RFtracTwee}{3{,}00}
\newcommand{\RFtracVier}{4{,}23}
\newcommand{\RtracGain}{41}
\newcommand{\RFreqNul}{0{,}43}
\newcommand{\RFreqTien}{1{,}34}
\newcommand{\RmarginNul}{7{,}0}
\newcommand{\RmarginTien}{2{,}2}
\newcommand{\RgradeMaxTwee}{29}
\newcommand{\RgradeMaxVier}{40}
\newcommand{\Rvmax}{0{,}67}
\newcommand{\Rvwork}{0{,}38}
\newcommand{\RTyawTwee}{147}
\newcommand{\RTresTwee}{23{,}0}
\newcommand{\RTyawVier}{207}
\newcommand{\RTresVier}{106}
\newcommand{\RscrubTwee}{16}
\newcommand{\RscrubVier}{51}
\newcommand{\RLwb}{100}
\newcommand{\RIstallTwee}{1{,}6}
\newcommand{\RIstallVier}{3{,}1}
\newcommand{\RIchanVier}{1{,}6}
\newcommand{\RPdissVier}{4{,}2}
\newcommand{\RbAgile}{159}
\newcommand{\RalphaOpt}{140}
\newcommand{\RalphaMin}{119}
\newcommand{\RalphaGain}{18}
\newcommand{\RRswept}{90{,}0}
\newcommand{\RDswept}{180{,}0}
\newcommand{\RDsweptSquare}{195{,}4}
\newcommand{\RdMaxFoot}{85}
\newcommand{\RbAccu}{133{,}2}
\newcommand{\RbArea}{98}
\newcommand{\RAframe}{109{,}4}
\newcommand{\RAframeSmal}{133{,}1}
\newcommand{\RbSmalMin}{98}
\newcommand{\RAframeBreed}{140{,}4}
\newcommand{\RAframeGain}{28}
\newcommand{\RbSweptMax}{154}
\newcommand{\RxfOpt}{54}
\newcommand{\RxfSmal}{nan}
\newcommand{\RIfree}{0{,}12}
\newcommand{\RUpack}{6{,}0}
\newcommand{\RUm}{4{,}25}
\newcommand{\RVdrop}{1{,}38}
\newcommand{\RRpack}{0{,}60}
\newcommand{\RtauStallZes}{70}
\newcommand{\RIstallZes}{1{,}10}
\newcommand{\RnNulZes}{200}
\newcommand{\RUbat}{6}
\newcommand{\RomegaNul}{14{,}8}
\newcommand{\RtauCont}{14{,}0}
\newcommand{\RomegaCont}{10{,}7}
\newcommand{\RnCont}{102}
\newcommand{\RvCont}{0{,}34}
\newcommand{\RIcontEen}{0{,}31}
\newcommand{\RetaCont}{11}
\newcommand{\RPmechCont}{0{,}30}
\newcommand{\RPelekCont}{2{,}60}
\newcommand{\RUmMos}{5{,}00}
\newcommand{\RvMos}{0{,}41}
\newcommand{\RkDuty}{28{,}2}
\newcommand{\RFcont}{0{,}87}
\newcommand{\RmMaxVlak}{1100}
\newcommand{\RmMaxSnel}{675}
\newcommand{\RmMaxVijf}{603}
\newcommand{\RmMaxTien}{381}
\newcommand{\RmAdvies}{603}
\newcommand{\RmComp}{409}
\newcommand{\RmFrameNu}{130}
\newcommand{\RmRuimte}{64}
\newcommand{\RmFrameMax}{194}
\newcommand{\RIcont}{0{,}32}
\newcommand{\RaNu}{1{,}33}
\newcommand{\RmMosVijf}{669}
\newcommand{\RmMosWinst}{11}
\newcommand{\RzAxle}{32}
\newcommand{\RzMotLo}{21}
\newcommand{\RzMotHi}{43}
\newcommand{\RzDeckEen}{46}
\newcommand{\RzDeckTwee}{66}
\newcommand{\RzAccuLo}{46}
\newcommand{\RzTop}{93}
\newcommand{\RhStandoff}{17}
\newcommand{\RhLTweeNegenAcht}{27}
\newcommand{\RzTyre}{64}
\newcommand{\RhMaxPitch}{54{,}5}
\newcommand{\RhMaxRoll}{61{,}2}
\newcommand{\RhMax}{54{,}5}
\newcommand{\RmTopMax}{129}
\newcommand{\RhMarge}{8{,}0}
\newcommand{\RRfloor}{441}
\newcommand{\RzSRvier}{58}
\newcommand{\RzLijn}{8}
\newcommand{\RclearGround}{21}
\newcommand{\Rbreakover}{58}
\newcommand{\Rxmotf}{18}
\newcommand{\RaccuW}{58}
\newcommand{\RaccuL}{61}
\newcommand{\Rclear}{4}
\newcommand{\Rxrear}{90}
\newcommand{\RquantBreed}{3{,}79}
\newcommand{\RquantWinst}{36}
\newcommand{\RbOpt}{98}
\newcommand{\RdOpt}{75}
\newcommand{\Rrw}{32}
\newcommand{\RDw}{64}
\newcommand{\Rwtyre}{25{,}9}
\newcommand{\Rtgb}{22{,}6}
\newcommand{\Rewheel}{14}
\newcommand{\RLmot}{70}
\newcommand{\Rhmot}{22}
\newcommand{\Rmu}{0{,}80}
\newcommand{\Rmuc}{0{,}20}
\newcommand{\RLframe}{160}
\newcommand{\Repsb}{1{,}5}
\newcommand{\Rxmotr}{52}
\newcommand{\Rcrr}{0{,}03}
\newcommand{\REd}{1}
\newcommand{\RNaxle}{20}
\newcommand{\RNshaft}{960}
\newcommand{\Rtaustall}{50}
\newcommand{\RIstallEen}{0{,}8}
\newcommand{\RholeX}{30}
\newcommand{\RholeY}{25}

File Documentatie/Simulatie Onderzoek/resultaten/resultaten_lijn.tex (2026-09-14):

% automatisch gegenereerd door onderzoek_lijnvolgen.m -- niet met de hand aanpassen
\newcommand{\LijnBaseEmax}{62}
\newcommand{\LijnBaseJit}{0{,}46}
\newcommand{\LijnBaseKp}{2291}
\newcommand{\LijnBaseOk}{30/30}
\newcommand{\LijnBaseTpar}{124{,}9}
\newcommand{\LijnBestBereik}{28{,}6}
\newcommand{\LijnBestEmax}{42}
\newcommand{\LijnBestJit}{0{,}018}
\newcommand{\LijnBestKd}{0{,}11}
\newcommand{\LijnBestKp}{226}
\newcommand{\LijnBestKster}{464}
\newcommand{\LijnBestKv}{0{,}68}
\newcommand{\LijnBestL}{45}
\newcommand{\LijnBestOk}{30/30}
\newcommand{\LijnBestPwmMm}{6{,}6}
\newcommand{\LijnBestSteek}{12{,}7}
\newcommand{\LijnBestTaud}{34}
\newcommand{\LijnBestTpar}{73{,}0}
\newcommand{\LijnBestVmax}{0{,}47}
\newcommand{\LijnBestVpar}{0{,}42}
\newcommand{\LijnDuur}{58}
\newcommand{\LijnEbereik}{28{,}5}
\newcommand{\LijnLmax}{92}
\newcommand{\LijnLmin}{120}
\newcommand{\LijnNkand}{76}
\newcommand{\LijnNrun}{30}
\newcommand{\LijnNtest}{10}
\newcommand{\LijnRkrap}{15}
\newcommand{\LijnSteekUni}{12{,}7}
\newcommand{\LijnTapeTienE}{33}
\newcommand{\LijnTapeTienOk}{100}
\newcommand{\LijnTaum}{83}
\newcommand{\LijnTd}{85}
\newcommand{\LijnVbocht}{0{,}35}
\newcommand{\LijnVnul}{0{,}47}

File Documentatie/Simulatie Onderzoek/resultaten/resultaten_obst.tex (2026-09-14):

% automatisch gegenereerd door onderzoek_obstakels.m -- niet met de hand aanpassen
\newcommand{\ObstAlfaKruisHi}{32}
\newcommand{\ObstAlfaKruisLo}{16}
\newcommand{\ObstBbeschA}{58}
\newcommand{\ObstBbeschB}{118}
\newcommand{\ObstBestAfst}{8{,}7}
\newcommand{\ObstBestAlfa}{43}
\newcommand{\ObstBestDslow}{29}
\newcommand{\ObstBestDstop}{28}
\newcommand{\ObstBestDzij}{45}
\newcommand{\ObstBestEcho}{nee}
\newcommand{\ObstBestEnc}{met encoders}
\newcommand{\ObstBestExtra}{46}
\newcommand{\ObstBestKzij}{1{,}0}
\newcommand{\ObstBestNf}{1}
\newcommand{\ObstBestOpst}{kruis2}
\newcommand{\ObstBestPr}{47}
\newcommand{\ObstBestPtest}{51}
\newcommand{\ObstBestPtestR}{46}
\newcommand{\ObstBestPv}{51}
\newcommand{\ObstBestPvHi}{61}
\newcommand{\ObstBestPvLo}{41}
\newcommand{\ObstBestRem}{tegenstroom}
\newcommand{\ObstBestStrat}{draai}
\newcommand{\ObstBestTmeas}{69}
\newcommand{\ObstBestV}{0{,}14}
\newcommand{\ObstBestWdraai}{1{,}2}
\newcommand{\ObstBestZonder}{kruis2}
\newcommand{\ObstBestZonderPv}{68}
\newcommand{\ObstDekKruisOpt}{100}
\newcommand{\ObstDekRechtA}{40}
\newcommand{\ObstDekRechtB}{82}
\newcommand{\ObstDeltaMax}{1{,}1}
\newcommand{\ObstDnodigA}{54}
\newcommand{\ObstDnodigB}{27}
\newcommand{\ObstDraaiMax}{19}
\newcommand{\ObstDraaiMin}{-30}
\newcommand{\ObstDraaiU}{23}
\newcommand{\ObstDuur}{32}
\newcommand{\ObstEncStap}{5{,}3}
\newcommand{\ObstGamDertig}{19}
\newcommand{\ObstGamZestig}{55}
\newcommand{\ObstHuidigPr}{0}
\newcommand{\ObstHuidigPv}{0}
\newcommand{\ObstHuidigT}{6}
\newcommand{\ObstKortPv}{55}
\newcommand{\ObstNkand}{70}
\newcommand{\ObstNtrain}{16}
\newcommand{\ObstNval}{100}
\newcommand{\ObstRcirkel}{1{,}1}
\newcommand{\ObstRvoor}{97}
\newcommand{\ObstRzwaai}{148}
\newcommand{\ObstRzwaaiKort}{115}
\newcommand{\ObstSremKort}{2{,}5}
\newcommand{\ObstSremRol}{9{,}0}
\newcommand{\ObstSremTegen}{0{,}6}
\newcommand{\ObstTlatDrie}{411}
\newcommand{\ObstTlatEen}{131}
\newcommand{\ObstVmaxDrie}{0{,}36}
\newcommand{\ObstVmaxEen}{0{,}47}
\newcommand{\ObstVmaxRol}{0{,}36}
\newcommand{\ObstWmaxDrie}{1{,}3}
\newcommand{\ObstWmaxEen}{4{,}4}

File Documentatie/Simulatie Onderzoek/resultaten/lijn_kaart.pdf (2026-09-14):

a. g

e

n

o

r

m

alis

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
look-ahead L [mm]

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
1.2 1.2

5

1.3 1.3

5

1.4 1.4

5

1.5 1.5

5

1.6 1.6

5

b. g

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
fwij

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
look-ahead L [mm]

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
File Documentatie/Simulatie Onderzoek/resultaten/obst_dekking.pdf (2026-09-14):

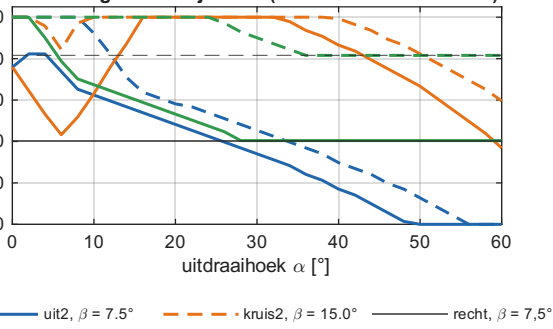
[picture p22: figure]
uit; aih; uis

0

## gedekte autobreedte [%]

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
a. d

e

k

## kin

g

v

a

n

d

e

## rij

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
2, -

=

1

5.0

°
k

r

uis

2, -

=

7.5

°

d

rie, -

=

7.5

°
d

rie, -

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
t, -

=

1

5

°

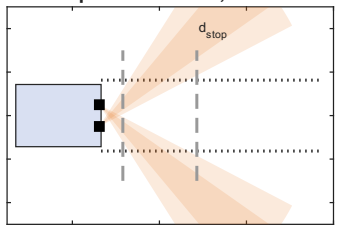
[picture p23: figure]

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
y [m]

0.2

0.10 0.1 0.2

b. o

p

## tim

u

m: k

r

## uis

2, ,

=

4

3

°

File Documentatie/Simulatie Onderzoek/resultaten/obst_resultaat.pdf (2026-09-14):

huidig

recht
kruis2

uit2
drie

recht+enc
kruis2+enc

uit2+enc
drie+enc

botsingsvrije ritten van 2 min [%]

0

20

40

60

80

100

a. validatie in 100 nieuwe arena's (95%-interval)

rommel
rustig

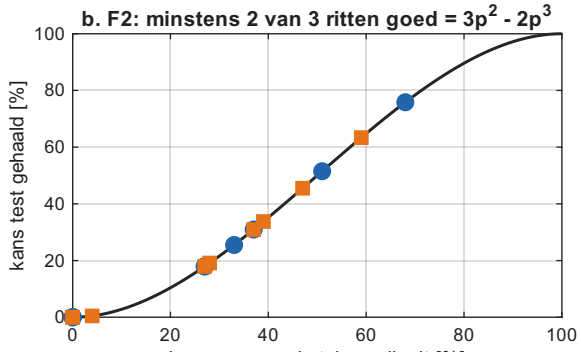
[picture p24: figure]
kans test gehaald [%]

kans p op een botsingsvrije rit [%] b. F2: minstens 2 van 3 ritten goed = 3p

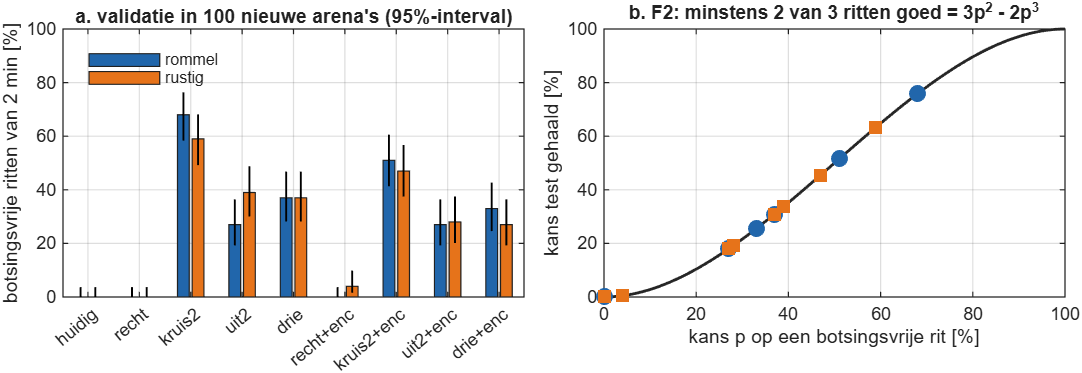
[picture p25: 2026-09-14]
Documentatie/Simulatie Onderzoek/resultaten/obst_resultaat.png

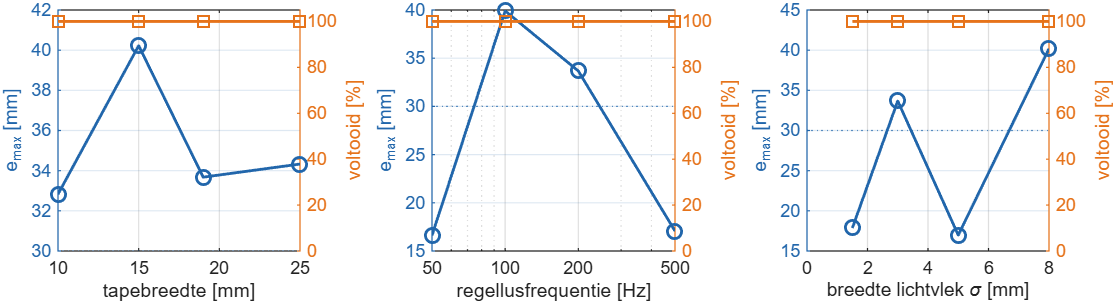
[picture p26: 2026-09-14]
Documentatie/Simulatie Onderzoek/resultaten/lijn_robuust.png

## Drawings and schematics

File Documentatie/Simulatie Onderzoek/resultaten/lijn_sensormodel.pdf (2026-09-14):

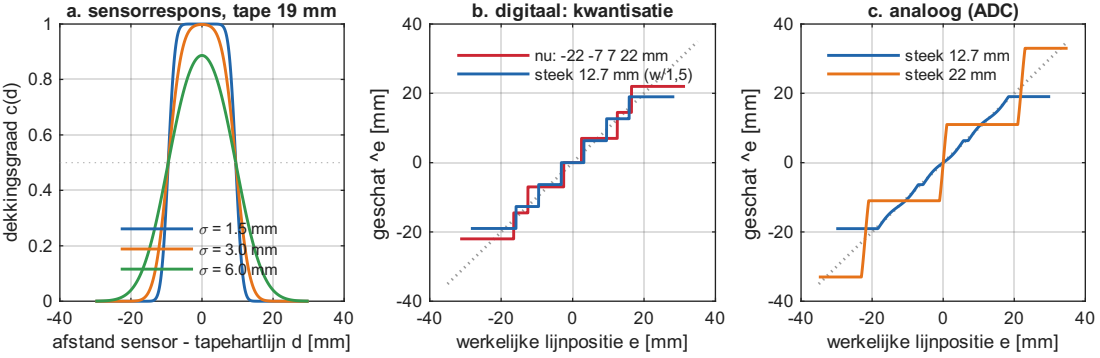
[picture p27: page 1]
dekkingsgraad c(d); geschat ^e [m; b. digitaal: kwantisatie; nu: -22 -7 7 22 mm steek 12.7 mm (w/1,5); c. analoog (ADC); steek 12.7 mm steek 22 mm

a. sensorrespons, tape 19 mm

< = 1.5 mm
< = 3.0 mm < = 6.0 mm

afstand sensor - tapehartlijn d [mm]

werkelijke lijnpositie e [mm]

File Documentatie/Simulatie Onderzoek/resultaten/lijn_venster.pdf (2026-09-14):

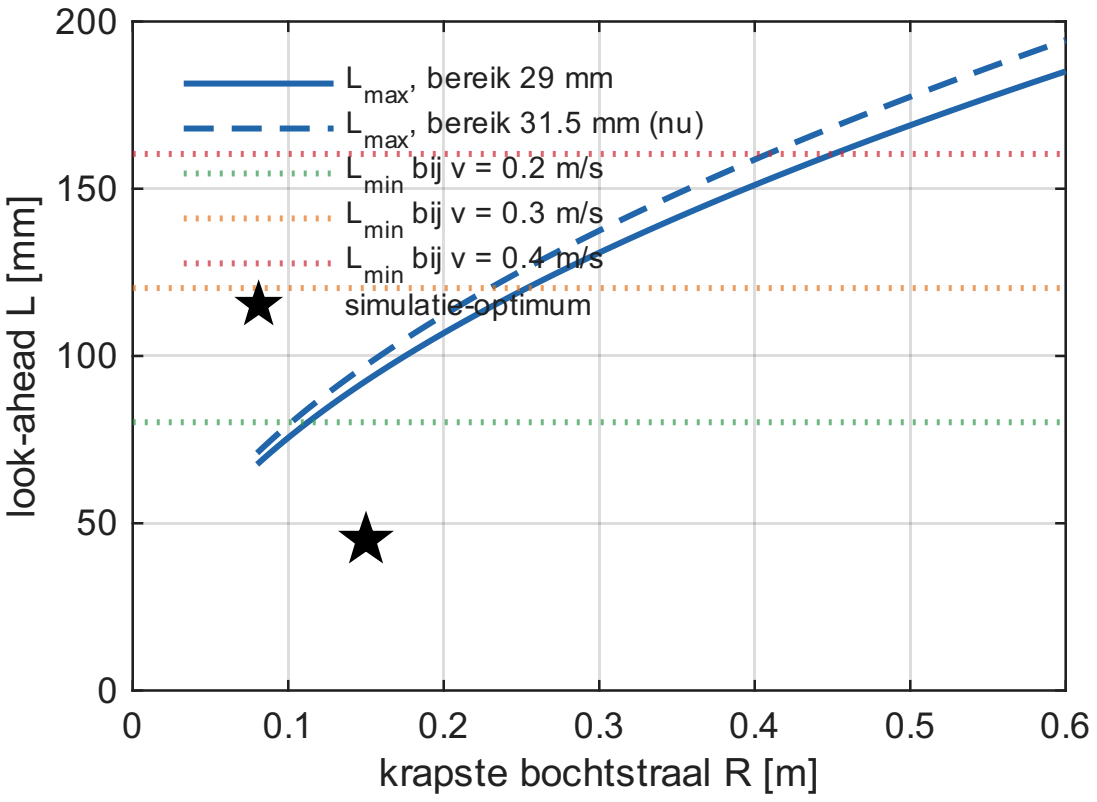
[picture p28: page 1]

L ax, b m L ax, b m L bij min | e reik 2 9 m m e reik 3 1.5 v = 0.2 m / s | m m ( n u )

look-ahead L [mm]

L bij min L bij min sim ula tie | v = 0.3 m / s v = 0.4 m / s -o p tim u m

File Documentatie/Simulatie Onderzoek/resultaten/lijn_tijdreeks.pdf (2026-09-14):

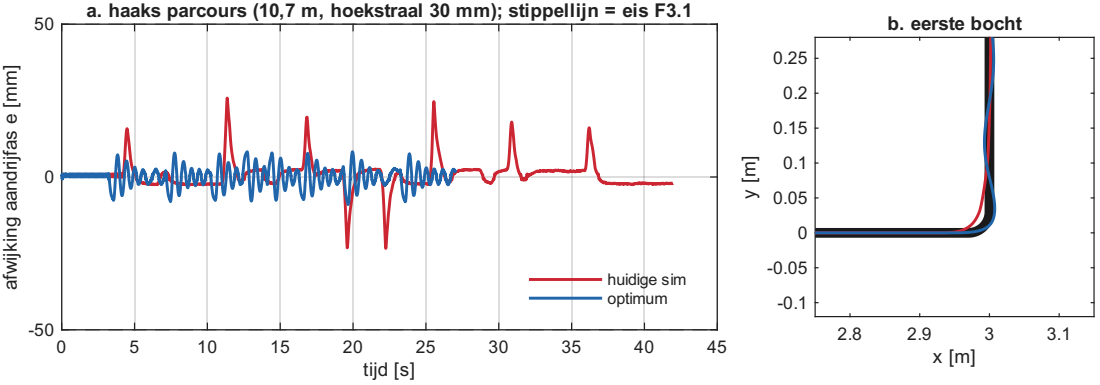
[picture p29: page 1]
tij; tip; ellij; eis; uidig; sim; tim

afwijking aandrijfas e [mm]

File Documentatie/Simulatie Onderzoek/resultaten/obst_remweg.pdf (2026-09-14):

a. r

e

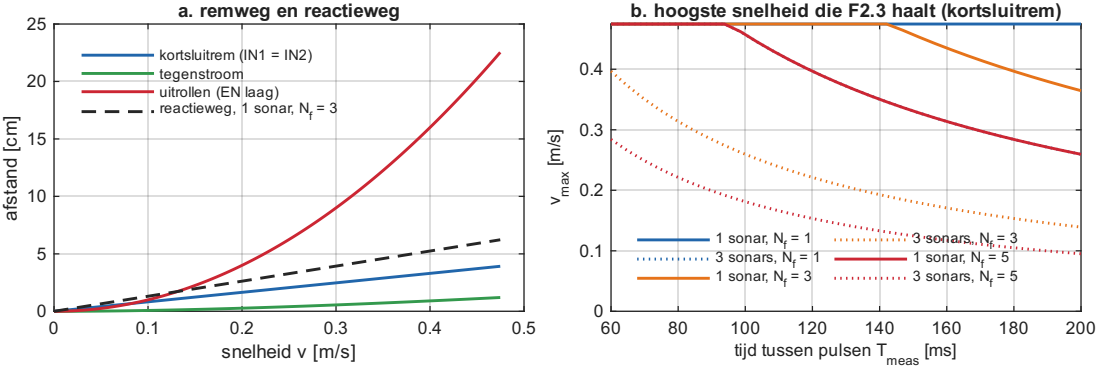
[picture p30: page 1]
elh; eid; afstand [cm]; tie; tij; uls; max [m/s]; die; alt; sluit

k o rt sluit re m t e g e n s t ro o m | (IN 1 = IN 2 )

uit rolle n ( E N la re a c tie w e g, 1 | a g ) s o n a r, N = 3 f

1 s o | n a r, N = 1 f | | 3 s o | n a rs, N = f | 3
3 s o 1 s o | n a rs, N = f n a r, N = 3 f | 1 | 1 s o 3 s o | n a r, N = 5 f n a rs, N = f | 5

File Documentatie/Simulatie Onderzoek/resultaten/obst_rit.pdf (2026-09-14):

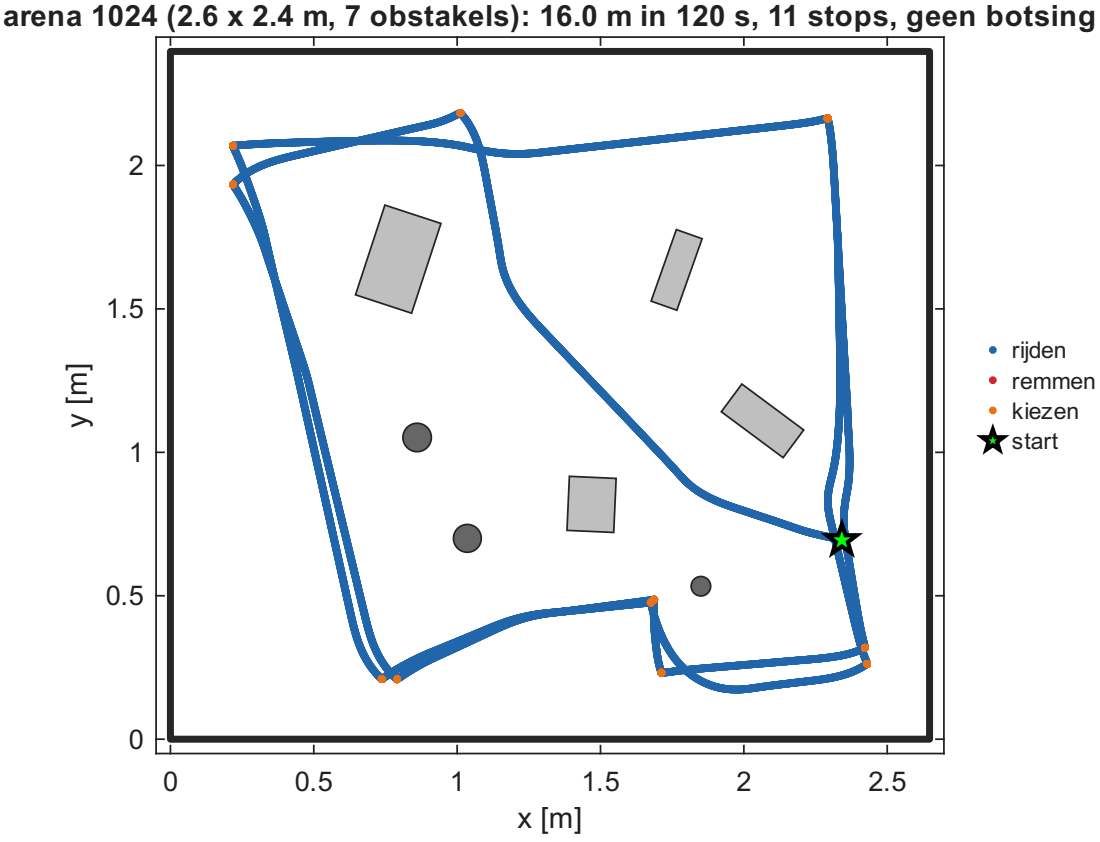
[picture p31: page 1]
rijden remmen kiezen start

arena 1024 (2.6 x 2.4 m, 7 obstakels): 16.0 m in 120 s, 11 stops, geen botsing

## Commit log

2026-08-31 Initial commit: project documents and assignment materials
    [ESE 2627 S1 beoordelingsformulier.xlsx]
2026-08-31 Rename Docs folder to School Docs
    [ESE 2627 S1 beoordelingsformulier.xlsx]
2026-08-31 Add working templates (agenda, notulen, productrapport) with placeholder company name and 6 team slots
2026-09-02 Restructure repo into Documentatie/Hardware/Software and add README
    Move School Docs and Templates under Documentatie/, add the Q-Dat Systems
    branding assets and the simulation side-research notes, and create empty
    Hardware/ and Software/ trees for the prototype work.
    Add a README with the company banner, a short project summary and the team.
    [ESE 2627 S1 beoordelingsformulier.xlsx]
2026-09-02 Add 3D models of the 4WD chassis
    Add the supplier STEP assembly and the per-part STL export under
    Hardware/3D Files/, plus a .gitattributes marking CAD and Office files as
    binary so Git does no line-ending conversion on them.
    [4WD assemblySTL - 4WD arduino buggy.stp-1 4WD buggy wheel v5_1.stp-1 4WD buggy wheel v5.stp-1.STL, 4WD assemblySTL - 4WD arduino buggy.stp-1 4WD buggy wheel v5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]
2026-09-02 Add simulation video and a slimmed-down Blender scene
    The original BlenderTrackSimulation.blend is 759 MB, far over the 100 MB
    GitHub limit. Almost all of that is duplicated data: the 24 cars in the
    scene each carry their own copy of the same 57 meshes, and the 19 unique
    textures are packed 36 times over.
    Add a slimmed copy that remaps byte-identical meshes and images onto one
    another and purges the orphans: 1426 objects unchanged, 37 MB instead of
    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
    [black-metal_2K_b77401f1-f6fb-48f2-82ea-40f958b1be15.blend, old-metal-old-iron_2K_c18af509-44cf-4be4-90ac-5318063e9ed3.blend, rubber-black_f13f1c89-05e0-42eb-8a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]
2026-09-02 Add a poster frame for the simulation video
    GitHub does not play video from the repository file view, only from
    attachments uploaded through its web editor, so link the video behind a
    still instead of promising an inline player.
2026-09-14 Add documentation, simulation research, frame analysis and 3D files
    Reorganise school docs and logos into new folders, add functional design,
    MoSCoW requirements, notes, UI sketches, MATLAB simulation study, frame
    analysis and SolidWorks/STL hardware files. The 134 MB Robot_Smart_Car_Kit_v2
    assembly is gitignored because it exceeds GitHub's file size limit.
    [3d print main body - plat.stl, 3d print main body.STL, ATmega328P_Xplained_Mini_release_rev4.SLDASM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]
2026-09-14 Add the full Robot Smart Car Kit assembly via Git LFS
    At 134 MB it is over GitHub's 100 MB file limit, so it goes through LFS
    instead of being ignored.
    [Robot_Smart_Car_Kit_v2.SLDASM]
